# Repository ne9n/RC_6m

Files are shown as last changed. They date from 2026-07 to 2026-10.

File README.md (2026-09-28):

# 6-Meter Ham Band RC Transceiver Project

This project focuses on designing and building a modern 50MHz (6-meter) radio control system using the amateur radio bands. It features a high-power 1W transmitter and a high-sensitivity receiver, integrated into a vintage Kraft 7 transmitter case with a modern digital encoder.

## 📁 Repository Structure

### 📡 TX Hardware
- [PA_Design_Details.md](file:///TX_Hardware/PA_Design_Details.md): 1W RD01MUS2 Power Amplifier design and filtering.
- [Digital_Encoder_Conversion.md](file:///TX_Hardware/Digital_Encoder_Conversion.md): Strategy for upgrading the Kraft 7 to digital.
- [Kraft_Digital_UI_Wiring.md](file:///TX_Hardware/Kraft_Digital_UI_Wiring.md): Pinout for ESP32, ADS1115, and OLED.
- [TX_Schematic_Blueprint.md](file:///TX_Hardware/TX_Schematic_Blueprint.md): Pin-to-pin wiring for KiCad TX entry.
- [TX_BOM.md](file:///TX_Hardware/TX_BOM.md): Parts list for building the transmitter.
- [Analog_Wiring_Harness.md](file:///TX_Hardware/Analog_Wiring_Harness.md): Physical wiring for Kraft sticks and auxiliary pots.
- [Case_Modification_Guide.md](file:///TX_Hardware/Case_Modification_Guide.md): Cutting, mounting, and mechanical integration for the Kraft case.
- [Battery_Management_Design.md](file:///TX_Hardware/Battery_Management_Design.md): LiPo conversion and USB-C charging for the Kraft case.

### 🛩️ RX Hardware
- [RX_Design_Details.md](file:///RX_Hardware/RX_Design_Details.md): Front-end LNA, LT5560 upconverter (118.2MHz LO, ~169MHz IF), and Si4463 FSK receiver.
- [Receiver_Servo_Design.md](file:///RX_Hardware/Receiver_Servo_Design.md): Servo bus wiring and MCU integration.
- [RX_PCB_Design_Guide.md](file:///RX_Hardware/RX_PCB_Design_Guide.md): Physical layout, grounding, and stackup for the RX board.
- [RX_Schematic_Blueprint.md](file:///RX_Hardware/RX_Schematic_Blueprint.md): Pin-to-pin wiring for KiCad schematic entry.
- [RX_Power_Supply_Design.md](file:///RX_Hardware/RX_Power_Supply_Design.md): Servo bus filtering and 3.3V LDO design.
- [RX_BOM.md](file:///RX_Hardware/RX_BOM.md): Parts list for building the receiver.

### 💻 Software
- [Kraft_7_Firmware_Skeleton.ino](file:///Software/Kraft_7_Firmware_Skeleton.ino): Full code structure for dual ADC and Si5351 handler.
- [Firmware_Protocol_Spec.md](file:///Software/Firmware_Protocol_Spec.md): GFSK modulation logic and 50MHz packet structure.
- [Si5351_GFSK_Driver.cpp](file:///Software/Si5351_GFSK_Driver.cpp): C++ driver for frequency-pulling modulation.
- [Firmware_Implementation.md](file:///Software/Firmware_Implementation.md): GFSK modulation and Si4463 packet reception over SPI.
- [Trim_Implementation.md](file:///Software/Trim_Implementation.md): Digital trim logic and math.
- [Project_Recommendations.md](file:///Software/Project_Recommendations.md): ELRS and SimpleTX project guidance.
- [Telemetry_Protocol_Design.md](file:///Software/Telemetry_Protocol_Design.md): 2-way 50MHz data packet definition.

### 📜 System Documentation
- [System_Requirements.md](file:///System_Docs/System_Requirements.md): High-level project specifications and architectural goals.
- [6m_ham_rc_transceiver_design.md](file:///System_Docs/6m_ham_rc_transceiver_design.md): System architecture and block diagrams.
- [Initial_BOM.md](file:///System_Docs/Initial_BOM.md): Complete parts list for ordering.
- [PCB_Layout_Strategy.md](file:///C:/radio/System_Docs/PCB_Layout_Strategy.md): RF grounding and isolation rules.
- [PCB_Footprint_Guide.md](file:///C:/radio/System_Docs/PCB_Footprint_Guide.md): SMT footprints and assembly instructions.
- [PCB_Footprint_Mapping.md](file:///C:/radio/System_Docs/PCB_Footprint_Mapping.md): KiCad library mapping for all BOM parts.
- [RF_Range_Analysis.md](file:///C:/radio/System_Docs/RF_Range_Analysis.md): Theoretical range and link budget for 1W on 50MHz.
- **Datasheets**:
    - [SPF5043Z.pdf](file:///C:/radio/System_Docs/Datasheets/SPF5043Z.pdf): High-performance GaAs pHEMT MMIC LNA (50-4000 MHz).
    - [Murata_SFE_10.7_Reference.md](file:///C:/radio/System_Docs/Datasheets/Murata_SFE_10.7_Reference.md): Technical specs for the 10.7MHz IF Ceramic Filter. *Superseded (2026-09-28): the 10.7MHz IF was replaced by a ~169MHz IF into an Si4463.*
- **KiCad Projects**:
    - [TX_50MHz_1W.kicad_sch](file:///C:/radio/KiCad_Projects/TX_50MHz_1W/TX_50MHz_1W.kicad_sch): Main Transmitter Schematic.
    - [RX_50MHz_SDR.kicad_sch](file:///C:/radio/KiCad_Projects/RX_50MHz_SDR/RX_50MHz_SDR.kicad_sch): Main Receiver Schematic.
    - [RX_50MHz_SDR.net](file:///C:/radio/KiCad_Projects/RX_50MHz_SDR/RX_50MHz_SDR.net): Netlist for Receiver layout.
    - [TX_50MHz_1W.net](file:///C:/radio/KiCad_Projects/TX_50MHz_1W/TX_50MHz_1W.net): Netlist for Transmitter layout.
    - [KiCad_Import_Instructions.md](file:///C:/radio/KiCad_Projects/KiCad_Import_Instructions.md): Step-by-step guide to building the boards.

---

## 🛠️ Project Goals
1.  **2-Way Communication**: Telemetry feedback (Battery, RSSI) from plane to transmitter.
2.  **High Power**: 1W output for superior range and reliability on the 50MHz band.
3.  **Modern Digital Link**: Moving away from old analog PPM to a robust GFSK digital protocol (ELRS-inspired).
4.  **Vintage Aesthetic**: Preserving the classic feel of the Kraft 7 transmitter while providing modern performance.

---
*Maintained by ne9n.*

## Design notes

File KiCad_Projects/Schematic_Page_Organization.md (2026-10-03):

# KiCad Schematic Page Organization

**Status:** TX and RX hierarchies are implemented and netlist-verified. TX now has a dedicated Battery + Power page; RX has Controller/I/O, RF Front End, and IF Radio child pages.

## Design Rules

- Keep the transmitter and airborne receiver as separate KiCad projects.
- Use one root sheet per project as a block-level overview. Put circuitry on child sheets by function and signal flow.
- Use hierarchical labels/sheet pins or global labels for signals that cross child-sheet boundaries. Keep nets local when both endpoints are on the same sheet.
- Use global power symbols for power rails and ground rather than adding a hierarchy pin for every power connection.
- Preserve reference designators where practical. Run ERC and regenerate netlists after moving circuitry.

## Transmitter Project: `TX_50MHz_1W`

| Sheet | File | Contents |
|---|---|---|
| Root | `TX_50MHz_1W.kicad_sch` | TX system overview and named inter-sheet connections to four child sheets. |
| Battery + Power | `TX_Battery_Power.kicad_sch` | J8/J9 battery and 5V inputs, LMR33630 buck converter, AP2112 3.3V regulator, and support passives. |
| Controller + TX RF | `TX_Controller_RF.kicad_sch` | ESP32-S3, ADS1115s, controls/OLED, Si5351A, PA, T/R switch, transmit filter/antenna, and telemetry LNA/mixer. |
| Telemetry IF | `TX_Telemetry_IF.kicad_sch` | 169 MHz IF network/match, Si4463, 30 MHz crystal, and associated passive network. |
| USB Interface | `USB_Interface.kicad_sch` | Existing USB interface and battery charger child sheet. |

### TX Inter-sheet Nets

| Net | From | To | Purpose |
|---|---|---|---|
| `LNA_OUT`, `MIX_IN`, `MIX_IN_N`, `MIX_LO_N`, `MIX_OUT_N`, `IF_OUT_P` | Controller + TX RF / LNA and mixer | Telemetry IF / passive IF network | Analog front-end to IF boundary. |
| `SI_SCLK`, `SI_MOSI`, `SI_MISO`, `SI_nSEL`, `SI_nIRQ`, `SI_SDN` | Controller + TX RF / ESP32-S3 | Telemetry IF / Si4463 | SPI data, chip select, interrupt, and shutdown. |
| `5V`, `V_BATT` | Battery + Power / input and regulators | Controller + TX RF / 5V rail and PA supply | Named root ports connect the battery/power sheet to the controller/RF page. |
| `+3V3`, `GND` | Global power symbols | Controller + TX RF, Telemetry IF, USB Interface, and Battery + Power | Global supply and ground. |
| `EN`, `BOOT_IO0`, `U0RXD`, `U0TXD` | Controller + TX RF / ESP32-S3 | USB Interface / CP2102N and auto-reset | USB serial and reset-control nets. |

I2C and `TR_SW_CTRL` remain local to Controller + TX RF. Cross-sheet signals appear as root sheet pins with matching child hierarchical labels; power rails use global power symbols.

## Receiver Project: `RX_50MHz_SDR`

| Sheet | File | Contents |
|---|---|---|
| Root | `RX_50MHz_SDR.kicad_sch` | System-level overview and child-sheet connections. |
| Controller / I/O | `RX_Controller_IO.kicad_sch` | ESP32-S3, servo headers, INA219, 3.3 V regulator, and MCU-side control. |
| RF Front End | `RX_RF_Front_End.kicad_sch` | Antenna, T/R switch, LNA/matching, 50 MHz filter, mixer, and Si5351A LO / telemetry drive. |
| IF Radio | `RX_IF_Radio.kicad_sch` | 169 MHz IF filter/match and receive-only Si4463. |

### RX Inter-sheet Nets

| Net | From | To | Purpose |
|---|---|---|---|
| `SDA`, `SCL` | Controller / ESP32 and INA219 | RF Front End / Si5351A | I2C control bus. |
| `TR_SW`, `RX_EN` | Controller / ESP32 | RF Front End / switch and mixer | RX/TX path control and mixer enable. |
| `IF_OUT_P`, `MIX_OUT_N` | RF Front End / LT5560 | IF Radio / IF filter | Mixer IF outputs into the 169 MHz filter. |
| `SI_SCLK`, `SI_MOSI`, `SI_MISO`, `SI_nSEL`, `SI_nIRQ`, `SI_SDN` | Controller / ESP32 | IF Radio / Si4463 | SPI, interrupt, and shutdown signals. |

The RX root page now shows named sheet pins and short net-label wires for every cross-sheet signal. Matching hierarchical labels on the child pages connect those ports. RF-only nets, servo signals, USB, and `5V_RAIL` stay local; `3V3` and `GND` use global power symbols.

## Power Nets

Use global power symbols for rails instead of hierarchy pins. The TX schematic uses `GND`, `+3V3`, and `V_BATT`; `5V` is an explicit inter-sheet signal. The RX schematic uses its existing `GND`, `+3V3`/`3V3`, and `5V_RAIL` nets. Keep these names as shown in each schematic.

## Conversion Notes

1. The TX root now exposes the cross-sheet nets as sheet pins; matching hierarchical labels are on each connected child page.
2. The TX and RX tables record root sheet pins and matching child hierarchical labels. Keep one consistent name per signal within each project.
3. The checked-in exported `.net` files are stale: they still show the old 10.7 MHz filter / ADC receive path and do not include the current Si4463 receive chain. Regenerate them from the updated schematics after the hierarchy conversion.
4. Run ERC on each project and inspect the generated netlists to confirm every listed cross-sheet signal reaches the intended pins.

## Related Design References

- [TX schematic blueprint](../TX_Hardware/TX_Schematic_Blueprint.md)
- [RX schematic blueprint](../RX_Hardware/RX_Schematic_Blueprint.md)
- [Project wiring instructions](work_instructions.md)

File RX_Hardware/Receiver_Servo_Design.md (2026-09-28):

# 6m RC Receiver: Back-End & Servo Connections

This document details the hardware and software required to turn the 50MHz RF signal into physical control for your airplane's servos.

## 1. Receiver Architecture (Back-End)

The RF deck upconverts the 50MHz signal to a ~169MHz IF and an **Si4463** FSK receiver demodulates it in hardware; the MCU (ESP32-S3) reads decoded packets over SPI (see `RX_Design_Details.md`). The MCU then generates **PWM (Pulse Width Modulation)** signals for the servos.

### 1.1 MCU Choice: ESP32-S3
The ESP32-S3 is recommended for the receiver because:
- **High Speed**: Dual-core 240MHz is plenty for packet handling, hopping and servo output.
- **PWM Peripherals**: The `MCPWM` (Motor Control PWM) hardware is perfect for generating jitter-free servo signals.
- **Tiny Form Factor**: Available in small modules (ESP32-S3-WROOM-1) suitable for aircraft.

---

## 2. Servo Connection Schematic

Standard RC servos use a 3-pin connector: **GND, 5V (VCC), and Signal (PWM)**.

### 2.1 Wiring Diagram
```mermaid
graph TD
    subgraph "50MHz RF Deck"
        RF["LT5560 Upconverter + 169MHz IF + Si4463"]
    end

    subgraph "Receiver Brain (ESP32-S3)"
        ADC["SPI (Si4463 packets)"]
        MCU["ESP32-S3 Core"]
        PWM["PWM Outputs (Ch 1-8)"]
    end

    subgraph "Servo Bus (Power Rail)"
        BEC["ESC / BEC (5V Input)"]
        S1["Servo 1 (Ail)"]
        S2["Servo 2 (Ele)"]
        S3["Servo 3 (Thr)"]
        S4["Servo 4 (Rud)"]
    end

    RF -- "Decoded packets" --> ADC
    ADC --> MCU
    MCU --> PWM
    PWM -- "Signal" --> S1 & S2 & S3 & S4
    BEC -- "5V Rail" --> S1 & S2 & S3 & S4
```

### 2.2 Servo Pin Mapping (ESP32)
| Channel | Function | ESP32 Pin | Note |
| :--- | :--- | :--- | :--- |
| **CH 1** | Aileron | GPIO 4 | 50Hz PWM, 1000-2000us (the old `ADC_IF` net on IO4 is removed with the Si4463 redesign, clearing this clash) |
| **CH 2** | Elevator | GPIO 5 | 50Hz PWM |
| **CH 3** | Throttle | GPIO 6 | Connects to ESC Signal |
| **CH 4** | Rudder | GPIO 7 | 50Hz PWM |
| **CH 5** | Aux 1 | GPIO 15 | Gear / Flaps |
| **CH 6** | Aux 2 | GPIO 16 | |
| **CH 7** | Aux 3 | GPIO 1 | |
| **CH 8** | Aux 4 | GPIO 2 | |

---

## 3. Power Management (The Servo Bus)

**CRITICAL**: Servos draw significant current (up to 2A during stalls). Do **NOT** power servos directly from the ESP32's 3.3V regulator.

1.  **Common Rail**: Create a high-current 5V rail (the "Servo Bus") on your PCB.
2.  **BEC Input**: Use the 5V output from your Electronic Speed Controller (ESC) to power this rail.
3.  **Isolation**: Add a large capacitor (470uF - 1000uF) on the 5V rail to prevent voltage dips (Brown-outs) when servos move rapidly, which could reset the ESP32.

---

## 4. PWM Firmware (ESP32 C++ Snippet)

Using the ESP32 `ESP32Servo` library for easy implementation.

```cpp
#include <ESP32Servo.h>

Servo aileron;
Servo elevator;

void setup() {
    // Standard RC PWM: 50Hz, 1000us min, 2000us max
    aileron.attach(4, 1000, 2000); 
    elevator.attach(5, 1000, 2000);
}

void updateServos(int ail_val, int ele_val) {
    // ail_val and ele_val are decoded from the 50MHz radio link
    aileron.writeMicroseconds(ail_val);
    elevator.writeMicroseconds(ele_val);
}
```

---

## 5. Physical Layout Recommendation
- **Servo Headers**: Use standard 3-pin 0.1" (2.54mm) male headers arranged in a row.
- **Antenna**: A 1.5m thin wire (28AWG) trailing from the plane. Ensure it is routed away from the servo wires to minimize interference.

---
*Created for the 50MHz Ham Band RC Project.*

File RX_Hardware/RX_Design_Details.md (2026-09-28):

# 6m RC Receiver Design Details (LT5560 + Si4463)

This document describes the design of the high-sensitivity receiver for the 50MHz RC link, focusing on the mixer and Intermediate Frequency (IF) stage.

## 1. Front-End (LNA)
- **Component**: **SPF5043Z** MMIC.
- **Function**: Provides ~15dB of gain with a very low noise figure (< 0.8dB).
- **Matching**: Requires a simple inductor/capacitor match for 50MHz at the input and output.
- **Protection**: A pair of BAV99 diodes should be placed at the input to protect the LNA from high-power pulses if the T/R switch fails.

---

## 2. Mixer Stage (Up-Converter)
The **LT5560** active mixer is kept, but it now **up-converts** the 6m signal to a VHF IF
instead of down-converting to 10.7MHz (see section 3 for why).

- **RF Input**: 50.100 - 51.000 MHz (from LNA / 50MHz BPF).
- **LO Input**: **118.200 MHz, fixed** (Si5351A CLK0, on its own PLL -- PLLA 709.2MHz, integer MultiSynth /6).
- **IF Output**: **IF = RF + LO** -> 168.300 - 169.200 MHz (US RC channels 50.800-50.980 -> 169.000-169.180 MHz).
  Sum mixing, so there is no spectral inversion: an FSK mark stays a mark.
- **Output network**: must now be tuned for ~169MHz rather than 10.7MHz. Both open-collector IF
  outputs need a DC path to VCC -- follow the LT5560 datasheet output network.
- **Spurs / image**: image = IF + LO ~ 287MHz; the 2xRF - LO = IF response sits at ~143.6MHz.
  Both are removed by the 50MHz BPF ahead of the mixer. LO (118.2MHz) and RF (50MHz)
  feedthrough are removed by the IF band-pass and the Si4463's own channel filter.

---

## 3. IF Filtering & Demodulation -- Si4463 packet receiver
- **IF Filter**: 3-pole LC band-pass, centre ~168.75MHz, ~3-5MHz bandwidth, 50 ohm (values TBD --
  design and verify with SPICE). Replaces the Murata SFE10.7 ceramic filter. It only needs to
  pass the hop band and reject LO/RF feedthrough; channel selectivity is done inside the Si4463.
- **Demodulator**: **Si4463-C2A-GM** (Silicon Labs EZRadioPRO, QFN-20, **active part**), used as
  a **receive-only** 2(G)FSK packet receiver at the 169MHz IF. Frequency range 142-1050MHz, so it
  cannot tune 50MHz directly -- hence the up-converter.
  - **RF input**: RXp/RXn through the differential LNA match from Silicon Labs AN643 (169MHz values).
  - **Reference**: its own **30.000MHz crystal** (internal tunable load caps, `GLOBAL_XO_TUNE`),
    not shared with the Si5351A, to keep LO spurs off the reference.
  - **Host interface**: SPI (<=10MHz, mode 0) + nIRQ + SDN to the ESP32-S3.
  - **Does in hardware**: channel filtering, demodulation, **AFC**, preamble + sync-word (0x1D4A)
    detection, packet FIFO, **RSSI**. Firmware only reads the 22-byte payload, checks CRC8 and
    drives the servos.
  - **Frequency hopping**: the LO stays fixed; each hop is just `START_RX` on the next Si4463
    channel number -- no Si5351 retuning or I2C traffic on the receive side.
- **Frequency error budget** (worst case, +-20ppm parts): TX carrier ~1kHz + LO ~2.4kHz + Si4463
  XO ~3.4kHz = ~6.8kHz -- more than the +-5kHz deviation. **Enable the Si4463 AFC**, and/or trim
  at build (Si5351 correction factor + `GLOBAL_XO_TUNE`).
- **IF choice**: 169MHz isn't an empty band anywhere (US land-mobile/paging nearby, EU 169.4MHz
  metering), so keep the IF section compact and shielded. If a local interferer shows up, the IF
  can be moved anywhere in ~142-200MHz with the LO kept <= ~150MHz.

  **Revision history -- why not the earlier approaches:**
  1. *IF undersampling (original)*: the ESP32-S3 ADC is capped at 83.3kSPS
     (`SOC_ADC_SAMPLE_FREQ_THRES_HIGH`), ~30x too slow for the 230kHz-wide 10.7MHz IF.
  2. *Single-chip FM-IF detectors* (MC3361/MC3372, SA604A, NJM2211): all obsolete (checked 2026-09-22).
  3. *CD74HC4046A PLL discriminator* (2026-09-22 revision): the HC4046 VCO is marginal at
     10.7MHz on 3.3V, needs a limited IF, and gives no AFC/RSSI/sync/CRC -- all left to firmware.
  4. *AX5043* (native 27-1050MHz, no conversion needed): out of production.
  5. *CC1101*: 300MHz minimum would need an LO > 250MHz, beyond the Si5351A's ~200MHz range.

---

## 4. T/R Switching
To protect the receiver during 1W transmission:
- **Component**: **BGS12PL6** RF Switch.
- **Isolation**: > 30dB at 50MHz.
- **Switching Speed**: < 1us (Critical for fast telemetry turnaround).

---

## 5. Summary Schematic Diagram

```mermaid
graph LR
    ANT["Antenna"] --> SW["RF Switch"]
    SW -- "TX Path" --> PA["1W PA"]
    SW -- "RX Path" --> BPF["50MHz BPF"]
    BPF --> LNA["SPF5043Z"]
    LNA --> MIXER["LT5560 Up-Mixer"]
    LO["Si5351A CLK0 (LO 118.2MHz)"] --> MIXER
    MIXER -- "IF 168.3-169.2MHz" --> IF_FILT["169MHz LC BPF"]
    IF_FILT --> MATCH["AN643 RX Match"]
    MATCH --> SI["Si4463 FSK Receiver"]
    XTAL["30MHz Crystal"] --> SI
    SI -- "SPI + nIRQ" --> MCU["ESP32-S3"]
```

---
*Reference: Analog Devices LT5560 Datasheet; Silicon Labs Si4464/63/61/60 Datasheet and AN643 (Si446x RX LNA matching).*

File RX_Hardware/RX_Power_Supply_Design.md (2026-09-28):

# 50MHz Receiver: Power Supply Design

This document describes the power distribution system for the aircraft-side receiver, converting high-current servo power to stable RF-grade 3.3V logic.

## 1. Power Source (BEC/ESC)
The receiver does not have its own battery. It draws power from the **5V or 6V rail** provided by the Electronic Speed Controller (ESC) or a standalone Battery Eliminator Circuit (BEC) via any of the servo headers.

- **Input Range**: 4.5V to 7.0V (Standard RC Servo Bus).
- **Current Requirement**: ~150mA (ESP32-S3 + RF stages) + Si4463 RX current (per datasheet, TBD) + Servo loads.

---

## 2. Power Architecture

```mermaid
graph LR
    SERVO[Servo Bus 5V-6V] --> FILT[LC Pi-Filter]
    FILT --> LDO[3.3V LDO AP2112K]
    LDO --> RF["RF Stages: LNA, Mixer, Synth, Si4463"]
    LDO --> MCU[ESP32-S3]
    SERVO --- SERVOS[Servos: Ail, Ele, Thr, Rud]
    BATT[Flight Battery] --> INA[INA219 Sensor]
    INA --> ESC[To ESC]
    INA -- I2C --> MCU
```

---

## 3. Voltage Regulation (3.3V)
We use a high-quality **Low Dropout Regulator (LDO)** instead of a switching buck converter to prevent switching noise from interfering with the sensitive 50MHz LNA.

### 3.1 Component: AP2112K-3.3
- **Output**: 3.3V @ 600mA.
- **Why**: Excellent ripple rejection and very low noise.

---

## 4. RF Noise Isolation
Servos generate significant "inductive kickback" and electrical noise. To protect the RF sensitivity, we implement two levels of filtering:

### 4.1 Input LC Filter (The "Moat")
A Pi-filter at the input of the LDO prevents servo noise from entering the logic rails.
- **L1**: 10 uH Power Inductor (0805 or 1206).
- **C1/C2**: 10 uF Ceramic Capacitors.

### 4.2 Local Decoupling
Each RF chip (SPF5043Z, LT5560) must have its own 10nF + 100pF capacitor pair located within 2mm of the VCC pin.

---

## 5. Reverse Polarity Protection
RC connectors can sometimes be plugged in backwards.
- **Protection**: A **Schottky Diode (e.g., SS14)** should be placed in series with the 5V input to the LDO to prevent magic smoke if the ESC is connected incorrectly.

---

## 6. Telemetry Monitoring (INA219)
To send battery status back to the ground station, an **INA219 I2C sensor** is placed in-line with the main flight battery.
- **V_BATT Monitoring**: Measures the 2S-4S LiPo voltage.
- **Current Monitoring**: Measures the total current draw of the propulsion system.
- **Interface**: Connects to the ESP32-S3 via the same I2C bus as the Si5351A.

---

## 7. Wiring Summary

| Point | Connection | Purpose |
| :--- | :--- | :--- |
| **Servo Rail (+)** | To Diode Anode | Main Power In |
| **Diode Cathode** | To LC Filter In | Protected Power |
| **LDO Vout** | To ESP32 & RF VCC | Clean 3.3V |
| **INA219 IN+** | To Battery (+) | Current Sensing In |
| **INA219 IN-** | To ESC (+) | Current Sensing Out |
| **Common GND** | Ground Plane | Return Path |

---
*Note: Ensure the ground plane under the LDO is solid to act as a small heatsink.*

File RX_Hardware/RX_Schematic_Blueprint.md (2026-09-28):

# 50MHz Receiver: KiCad Schematic Blueprint

## Visual Schematic Reference
RX Schematic Reference

## 1. Functional Block Diagram

```mermaid
graph LR
    ANT[Antenna] --> SW[BGS12PL6 T/R Switch]
    SW -- RX Path --> LNA_MATCH[Input Match]
    LNA_MATCH --> LNA[SPF5043Z]
    LNA --> BPF[50MHz BPF]
    BPF --> MIX[LT5560 Mixer]
    LO[Si5351A CLK0 LO 118.2MHz] --> MIX
    SW -- TX Path --> TELEM_DRIVE[Si5351A CLK1]
    MIX -- "IF 168.3-169.2MHz" --> IF_FILT[169MHz LC BPF]
    IF_FILT --> RXMATCH[AN643 RX Match]
    RXMATCH --> SI4463[Si4463 FSK Receiver]
    SI4463 -- SPI + nIRQ --> ESP
    BATT[Flight Battery] --> INA[INA219 Sensor]
    INA --> ESC[To ESC]
    INA -- I2C --> ESP[ESP32 MCU]
```

---

## 2. Component Netlist (Pin-to-Pin)

### 2.1 RF Switch (T/R Switch)
**IC: BGS12PL6 (TSLP-6)**

| Pin | Name | Connection | Note |
| :--- | :--- | :--- | :--- |
| 1 | RF2 | To Si5351A CLK1 (via 100pF) | Telemetry TX Path |
| 2 | GND | Ground Plane | |
| 3 | RF1 | To LNA Match Input | Control RX Path |
| 4 | CTRL | ESP32 IO10 (TR_SW) | High = TX, Low = RX |
| 5 | ANT | To Antenna Header | 50 Ohm Port |
| 6 | VDD | 3.3V Rail | Decouple with 0.1uF |

### 2.2 RF Front-End (LNA)
**IC: SPF5043Z (SOT-343)**

| Pin | Name | Connection | Note |
| :--- | :--- | :--- | :--- |
| 1 | RFin | From Switch RF1 (via 100pF) | 50 Ohm Trace |
| 2 | GND | Ground Plane | Use multiple vias |
| 3 | RFout/VCC | To Mixer (via 100pF Cap + RFC) | Power fed via Inductor |
| 4 | GND | Ground Plane | |

### 2.3 Mixer Stage (up-converter, 50MHz -> 169MHz IF)
**IC: LT5560 (DFN-8)**

| Pin | Name | Connection | Note |
| :--- | :--- | :--- | :--- |
| 1 | IN+ | From LNA Output (C_coupling) | RF Input |
| 2 | IN- | AC Ground (100pF to GND) | |
| 3 | EN | ESP32 IO21 (RX_EN) | Logic High to Enable |
| 4 | VCC | 3.3V Rail | Decouple with 10nF |
| 5 | OUT+ | To 169MHz IF BPF (via output match) | IF Output, ~169MHz; DC path to VCC per LT5560 datasheet |
| 6 | OUT- | AC Ground (10nF to GND) | Also needs its DC path to VCC (open collector) |
| 7 | LO+ | From Si5351A CLK0 | Local Oscillator, 118.200MHz fixed |
| 8 | LO- | AC Ground (100pF to GND) | |

### 2.4a IF Band-Pass Filter (replaces 10.7MHz ceramic filter)
3-pole LC band-pass, 50 ohm, centre ~168.75MHz, ~3-5MHz bandwidth (passes 168.3-169.2MHz).
Rejects LO (118.2MHz) and RF (50MHz) feedthrough from the mixer. Values TBD -- design and
verify with SPICE before layout.

### 2.4b FSK Packet Receiver
**IC: Si4463-C2A-GM (QFN-20, 4x4mm, exposed pad)** -- see `RX_Design_Details.md` section 3.
Receive-only: the TX and TXRAMP pins are left open and the chip is never put in TX state.
Replaces the CD74HC4046APWR PLL discriminator and the IF/baseband-to-ADC path (`ADC_IF` on IO4 is deleted).

| Pin | Name | Connection | Note |
| :--- | :--- | :--- | :--- |
| 1 | SDN | ESP32 IO18 (SI_SDN) | High = shutdown; drive low to run |
| 2 | RXp | From IF BPF via RX match | Differential LNA match per Silicon Labs AN643 (169MHz) |
| 3 | RXn | From IF BPF via RX match | |
| 4 | TX | Not Connected | Receive-only |
| 5 | NC | Not Connected | |
| 6 | VDD | 3.3V Rail | Decouple 100nF + 1uF |
| 7 | TXRAMP | Not Connected | Receive-only |
| 8 | VDD | 3.3V Rail | Decouple 100nF + 1uF (+10pF close to the pin) |
| 9 | GPIO0 | Test point | Optional RX_STATE |
| 10 | GPIO1 | Test point | Optional CTS (CTS is also polled over SPI) |
| 11 | nIRQ | ESP32 IO17 (SI_nIRQ) | Open drain, 10k pull-up to 3.3V |
| 12 | SCLK | ESP32 IO12 (FSPICLK) | SPI <=10MHz, mode 0 |
| 13 | SDO | ESP32 IO13 (FSPIQ) | MISO |
| 14 | SDI | ESP32 IO11 (FSPID) | MOSI |
| 15 | nSEL | ESP32 IO14 | Chip select (software-driven via GPIO matrix; IO10 is the T/R switch CTRL) |
| 16 | XOUT | 30.000MHz Crystal | Internal load caps (`GLOBAL_XO_TUNE`), no external caps |
| 17 | XIN | 30.000MHz Crystal | |
| 18 | GND | Ground Plane | |
| EP | GND | Ground Plane | Via-stitched exposed pad |

ESP32 pins: FSPI IOMUX pins for SCLK/MOSI/MISO, with CS on IO14 because IO10 is the T/R switch
CTRL. As captured in `RX_50MHz_SDR.kicad_sch` (U9) on 2026-09-28.

### 2.4 Synthesizer
**IC: Si5351A (MSOP-10)**

| Pin | Name | Connection | Note |
| :--- | :--- | :--- | :--- |
| 1 | VDD | 3.3V Rail | Decouple 0.1uF |
| 2 | XA | 26MHz Crystal | |
| 3 | XB | 26MHz Crystal | |
| 4 | SCL | ESP32 GPIO 9 | I2C Clock |
| 5 | SDA | ESP32 GPIO 8 | I2C Data |
| 6 | CLK0 | To LT5560 Pin 7 | LO Output, 118.200MHz fixed, PLLA |
| 7 | CLK1 | To BGS12 Pin 1 (via 100pF) | Telemetry TX Output, PLLB (FSK updates never touch the LO) |

### 2.5 Telemetry Sensor
**IC: INA219 (SOT-23-8)**

| Pin | Name | Connection | Note |
| :--- | :--- | :--- | :--- |
| 1 | IN+ | Main Battery Positive | Source |
| 2 | IN- | ESC Positive Lead | Load |
| 3 | GND | System Ground | |
| 4 | VS | 3.3V Rail | |
| 5 | SCL | I2C Clock (Bus) | |
| 6 | SDA | I2C Data (Bus) | |
| 7 | A0 | GND | Address 0x40 |
| 8 | A1 | GND | |

### 2.6 Power Supply (3.3V Regulator)
**IC: AP2112K-3.3 (SOT-23-5)**

| Pin | Name | Connection | Note |
| :--- | :--- | :--- | :--- |
| 1 | VIN | From Servo 5V (via SS14 Diode) | LC Filtered |
| 2 | GND | Ground Plane | |
| 3 | EN | Connect to VIN | Always On |
| 4 | NC | Not Connected | |
| 5 | VOUT | 3.3V Logic Rail | Decouple 10uF |

---

## 3. Passive Component Values (50MHz)

| RefDes | Value | Purpose |
| :--- | :--- | :--- |
| **C_coupl** | 100 pF | DC Blocking (RF Path) |
| **L_match** | 220 nH | Input Matching for 50MHz |
| **C_decoup** | 10 nF | High-frequency bypassing |
| **RFC** | 1.0 uH | RF Choke for LNA Power |
| **IF_FILT** | 169 MHz | 3-pole LC band-pass, ~3-5MHz BW, 50 ohm -- values TBD (SPICE) |
| **LT5560 IF match** | TBD | Output network for ~169MHz (replaces the 10.7MHz output match) |
| **Si4463 RX match** | TBD | Differential LNA match, 169MHz values from Silicon Labs AN643 |
| **Y (Si4463)** | 30.000 MHz | Crystal, 3225, <=+-10ppm preferred; no load caps (internal) |
| **R_nIRQ** | 10 kOhm | nIRQ pull-up to 3.3V |
| **C_Si4463** | 100nF + 1uF per VDD pin | Si4463 decoupling |

---

## 4. KiCad Library Suggestions
- **ESP32-S3**: Use the `Espressif` official KiCad library.
- **Si4463**: `RF:Si4463` in the stock KiCad library, footprint `Package_DFN_QFN:QFN-20-1EP_4x4mm_P0.5mm_EP2.6x2.6mm_ThermalVias`.
- **Si5351A**: Found in the `RF_Synthesizer` library.
- **SPF5043Z**: You may need to create a custom SOT-343 symbol, or use a generic 4-pin LNA symbol.
- **LT5560**: Use a generic `DFN-8-1EP_2x2mm` footprint.

## 5. Next Steps in KiCad
1.  **Symbols**: Add the ESP32-S3, Si5351A and Si4463 from the standard libraries. Delete the 10.7MHz filter and the `ADC_IF` net.
2.  **Custom Symbols**: Create the LT5560 and SPF5043Z symbols using the pin tables above.
3.  **Hierarchy**: Use **Global Labels** for `3.3V`, `GND`, `SDA`, and `SCL` to keep the schematic clean.
4.  **Grounding**: Ensure the **Exposed Pad (EP)** on the LT5560 is connected to the GND net.

---
*Created for the 6m RC Receiver Build.*

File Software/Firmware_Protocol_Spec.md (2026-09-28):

# Kraft-6M: Firmware Implementation & Protocol Guide

This document details the software logic required to run the 50MHz digital RC link using the ESP32-S3 and Si5351A.

## 1. Modulation Logic (Si5351A GFSK)
Unlike 2.4GHz chips (LoRa/CC2500), the Si5351A is a clock generator. To perform **Gaussian Frequency Shift Keying (GFSK)**, we must "pull" the frequency of the oscillator in real-time.

### 1.1 Bit Representation
- **Center Frequency ($f_c$):** 50.100 MHz
- **Frequency Deviation ($\Delta f$):** ±5 kHz (project standard -- older docs/code used ±2.4 kHz; the Si4463 receivers are configured for ±5 kHz, so the TX must match)
- **Logic '1':** $f_c + 5$ kHz
- **Logic '0':** $f_c - 5$ kHz

### 1.2 Implementation
We use the Si5351's **VCXO (Voltage Controlled Crystal Oscillator)** capability or rapidly update the `MultiSynth` registers via I2C.
- **Data Rate:** 2400 bps or 4800 bps (to keep bandwidth narrow and range high).
- **Encoding:** **NRZ, no whitening** (bring-up default). The Si4463 receiver can't decode 8b/10b, so that option is dropped; Manchester is supported in Si4463 hardware and is the fallback if long runs cause bit errors (doubles the on-air symbol rate).
- **Preamble:** at least **5 bytes (40 bits) of alternating `0x55`** ahead of the sync word, so the Si4463's AFC and preamble detector settle.
- **Separate PLLs:** the Si5351A's CLK0 (FSK carrier) and CLK1 (118.2MHz receive LO) sit on PLLA and PLLB, so FSK updates never disturb the LO.

---

## 2. Packet Structure (24 Bytes)
Each frame transmitted every 20ms (50Hz) follows this structure:

| Byte | Field | Description |
| :--- | :--- | :--- |
| 0-1 | **Sync Word** | 0x1D4A (detected by the Si4463 packet handler; bytes 2-23 are the fixed-length 22-byte payload) |
| 2-17| **Channels** | 8 Channels x 16-bits (from ADS1115) |
| 18 | **Flags** | Failsafe bit, Telemetry request bit |
| 19-22| **ID** | 32-bit Unique Transmitter ID |
| 23 | **CRC8** | Cyclic Redundancy Check (Polynomial: 0x07) -- computed/checked in firmware; Si4463 hardware CRC disabled |

---

## 3. Transmitter (TX) Logic Flow
1.  **Read ADCs**: Poll both ADS1115 modules for stick and aux knob positions.
2.  **Apply Trims**: Add/Subtract the digital trim values stored in ESP32 NVS.
3.  **Pack Frame**: Convert 16-bit values into the 24-byte buffer.
4.  **Bit-Bang RF**:
    - Iterate through the buffer bit-by-bit.
    - Change Si5351 CLK0 frequency for each bit.
    - Maintain precise timing using ESP32 High-Resolution Timers (`esp_timer`).
5.  **Listen for Telemetry**: Briefly switch the receiver (if implemented) or check for ACKs.

---

## 4. Receiver (RX) Logic Flow (Si4463)
The 6m signal is upconverted to ~169MHz (LT5560 + fixed 118.2MHz Si5351A LO) and demodulated by an **Si4463**; the ESP32-S3 reads finished packets over SPI. (The earlier SDR/IF-sampling and 4046 PLL-discriminator flows are superseded -- see `Firmware_Implementation.md`.)
1.  **Init**: SDN low, wait for POR, load the WDS/Radio Configurator config (`radio_config_si4463.h`) over SPI, polling CTS. AFC enabled.
2.  **Listen**: `START_RX` on the current hop channel, fixed packet length.
3.  **Packet**: on nIRQ (PACKET_RX), read the 22-byte payload from the RX FIFO and the latched RSSI.
4.  **CRC Check**: If the firmware CRC8 passes, update the PWM outputs for the servos.
5.  **Failsafe**: If no valid packet is received for 500ms, move servos to neutral/preset.

---

## 5. Frequency Hopping (FHSS)
To comply with Ham Radio best practices and avoid interference:
- Define a table of 16 frequencies (e.g., 50.1, 50.2, ... 50.8 MHz).
- Both TX and RX hop to the next frequency every 100ms.
- **Receive side**: hopping is done by the **Si4463 channel number** (`START_RX` on the next channel; channel step = hop spacing). The 118.2MHz LO stays fixed -- no Si5351A retune or I2C traffic on the receive side per hop. The transmit side still retunes Si5351A CLK0.
- **Note**: the example table (50.1-50.8 MHz) overlaps the 6m weak-signal CW/SSB segment (50.0-50.3 MHz). The US RC channels are 50.800-50.980 MHz -- review the hop table before use.
- Hopping sequence is determined by the 32-bit `Transmitter ID`.

---
*Created for the Kraft-6M Project.*

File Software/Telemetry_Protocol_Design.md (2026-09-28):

# 50MHz RC Telemetry Protocol Design

This document defines the 2-way data packet structure for sending airplane status (telemetry) back to the Kraft transmitter over the 50MHz link.

## 1. Physical Layer (PHY)
- **Modulation**: GFSK (Gaussian Frequency Shift Keying).
- **Data Rate**: 50 kbps (Balanced for range vs latency).
- **Frequency**: 50.0 - 54.0 MHz (User selectable).
- **Duplex**: Time Division (TDD). 90% TX (Control), 10% RX (Telemetry).
- **Receiver (TX board)**: the telemetry is received by an **Si4463** (LT5560 upconversion to a ~169MHz IF, Si5351A LO fixed at 118.2MHz -- see `RX_Hardware/RX_Design_Details.md`). The Si4463 has one PHY configuration, so the telemetry downlink must use the **same PHY as the control link**: 2FSK/2GFSK, 2400 bps, +-5kHz deviation, >=5-byte `0x55` preamble, `0x1D4A` sync word, NRZ, fixed length (see `Firmware_Protocol_Spec.md`). The 50 kbps rate and 1-byte `0x99` sync below are **superseded** -- the Si5351A I2C modulator can't reach 50 kbps anyway.

---

## 2. Packet Structure

Each telemetry packet is **12 bytes** long to keep the transmission window short.

| Byte | Field | Description | Range |
| :--- | :--- | :--- | :--- |
| 0 | **Sync** | Sync Word (0x99) -- superseded: the Si4463 packet handler detects the 2-byte `0x1D4A` sync ahead of this byte | Fixed |
| 1 | **Device ID** | Unique ID for the Receiver | 0-255 |
| 2-3 | **Batt_V** | Main Flight Battery Voltage (mV) | 0 - 65535 mV |
| 4-5 | **Current** | Instantaneous Current (mA) | 0 - 65535 mA |
| 6 | **RSSI** | Signal Strength at Airplane (latched RSSI from the RX board's Si4463) | -128 to 0 dBm |
| 7 | **Link Quality**| Packet success rate | 0 - 100% |
| 8-9 | **Altitude** | Barometric or GPS altitude (m) | Signed Integer |
| 10 | **Flags** | Alarm bits (Low Batt, Failsafe) | Bitmask |
| 11 | **CRC8** | Error Checking (Dallas/Maxim) | Calculated |

---

## 3. Firmware Logic (ESP32-S3)

### 3.1 On the Airplane (RX)
Every 100ms, the receiver stops listening for control pulses, switches the Si5351A to the Telemetry frequency, and bursts the 12-byte packet.

### 3.2 On the Transmitter (TX)
The transmitter listens in the "gap" between its control frames. If a valid telemetry packet is received:
1.  **CRC Check**: Validate packet integrity (in firmware; the Si4463's hardware CRC is disabled). The packet arrives over SPI from the TX board's Si4463 on nIRQ (PACKET_RX); the Si4463's latched RSSI gives the ground-side signal strength.
2.  **Display Update**: Push the `Batt_V` and `RSSI` to the SH1106 OLED display.
3.  **Haptic/Audio**: Trigger a beep if `Flags` bit 0 (Low Battery) is set.

---

## 4. Telemetry Alarm Thresholds

| Sensor | Warning (Beep) | Critical (Continuous) |
| :--- | :--- | :--- |
| **LiPo 3S** | 10.8V (3.6V/cell) | 10.2V (3.4V/cell) |
| **RSSI** | -95 dBm | -105 dBm (Risk of Failsafe) |
| **Link Quality**| < 70% | < 50% |

---

## 5. Next Steps
- Implement the `CRC8` calculation function in the ESP32 code.
- Add an **INA219 I2C Current Sensor** to the receiver BOM for high-accuracy current/voltage sensing.

---
*Reference: ExpressLRS (ELRS) Telemetry Format & CRSF Protocol.*

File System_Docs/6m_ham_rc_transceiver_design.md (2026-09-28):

# 6m (50MHz) Amateur Radio RC Transceiver Design

This document details the design for a modern, high-performance 2-way digital radio control and telemetry system operating in the 50MHz (6-meter) Amateur Radio band.

## 1. Project Overview
- **Frequency Band**: 50.0 – 54.0 MHz (Target: 50.8 – 51.0 MHz RC Window).
- **Communication Type**: 2-Way Digital Link (Control + Telemetry).
- **Modulation**: GFSK (Gaussian Frequency Shift Keying).
- **Architecture**: Si5351A carrier/LO + LT5560 upconverting mixer + **Si4463** FSK receiver (6m upconverted to a ~169MHz IF) - all in-production parts. (Revised 2026-09-28: replaces the SA612 / 10.7MHz IF / software-demod receiver.)

---

## 2. System Architecture

```mermaid
graph TD
    subgraph "Ground Station (TX - 1W)"
        G_MCU["ESP32 (ELRS Logic)"]
        G_Si["Si5351A (Freq Gen)"]
        G_PA["RD01MUS1 (1W PA)"]
        G_LPF["7-Pole Low Pass Filter"]
        G_Switch["RF T/R Switch"]
        G_Whip["1.5m Telescoping Whip"]

        G_MCU -- "I2C (Freq Shift)" --> G_Si
        G_Si -- "50MHz" --> G_PA
        G_PA --> G_Switch
        G_Switch <--> G_LPF <--> G_Whip
        G_Switch -- "RX Path" --> G_LNA["SPF5043Z LNA + LT5560 Mixer"]
        G_Si -- "LO 118.2MHz (CLK1)" --> G_LNA
        G_LNA -- "169MHz IF (LC BPF)" --> G_RX["Si4463 FSK Receiver"]
        G_RX -- "SPI (packets, RSSI)" --> G_MCU
    end

    subgraph "Airplane Receiver (RX - Mini)"
        A_MCU["ESP32-S3"]
        A_Si["Si5351A (LO/TX)"]
        A_Mixer["SPF5043Z LNA + LT5560 Mixer"]
        A_RX["Si4463 FSK Receiver"]
        A_BPF["50MHz Bandpass"]
        A_Wire["1.5m Trailing Wire"]

        A_Wire <--> A_BPF <--> A_Mixer
        A_Si -- "LO 118.2MHz (CLK0)" --> A_Mixer
        A_Mixer -- "169MHz IF (LC BPF)" --> A_RX
        A_RX -- "SPI (packets, RSSI)" --> A_MCU
        A_Si -- "Telemetry TX" --> A_BPF
        A_MCU -- "I2C" --> A_Si
    end

    G_Whip -. "50MHz Control" .-> A_Wire
    A_Wire -. "Telemetry" .-> G_Whip
```

---

## 3. Key Components

### 3.1 RF & Logic
| Component | Part Number | Role | Description |
| :--- | :--- | :--- | :--- |
| **Frequency Gen** | [Si5351A-B-GT](https://www.silabs.com/timing/clock-generators/si5351-any-frequency-i2c-programmable-clock-generator) | TX & LO | Generates 50MHz carrier and handles FSK modulation via I2C register pulling. |
| **Power Amp** | [RD01MUS1](https://www.mitsubishielectric.com/semiconductors/content/product/highfrequency/rfmosfet/rd01mus1.pdf) | TX Boost | 1W VHF Silicon MOSFET. Provides robust range for the ground link. |
| **Mixer** | LT5560 | Receiver (both boards) | Active mixer, used as an **upconverter**: 50MHz + 118.2MHz LO -> ~169MHz IF. Replaces the SA612AD. |
| **FSK Receiver** | Si4463-C2A-GM | Receiver (both boards) | Silicon Labs EZRadioPRO, 142-1050MHz, receive-only here. Hardware 2FSK demod, AFC, preamble/sync detect, FIFO, RSSI; ESP32 reads packets over SPI. |
| **LNA** | [SPF5043Z](https://www.qorvo.com/products/p/SPF5043Z) | Front-End | Low-noise amplifier to maximize sensitivity. |

### 3.2 Microcontrollers
- **Ground Station**: **ESP32-S3**. Powerful enough to run the ExpressLRS (ELRS) stack, with integrated WiFi for smartphone configuration and firmware updates.
- **Airplane RX**: **ESP32-S3**. Reads demodulated packets from the Si4463 over SPI and drives the servos; no IF sampling or software demodulation. (The STM32L412 / software-demod plan is superseded.)

---

## 4. Design Specifics

### 4.1 FSK Modulation Technique
The Si5351A is modulated by the MCU updating the `MSx_P1`, `MSx_P2`, and `MSx_P3` registers over I2C.
- **Center Frequency**: 50.800 MHz.
- **Deviation**: ±5 kHz (project standard; older docs said ±2.4 kHz). Must match the Si4463 receiver configuration.
- **Update Rate**: For a 2400 baud link, the registers should be updated at approximately 10kHz to ensure smooth frequency transitions (GFSK).

### 4.2 Receiver Intermediate Frequency (IF)
Both receivers (airplane RX and the ground station's telemetry receiver) use single-conversion **upconversion** into an Si4463, which doesn't tune down to 50MHz (range 142-1050MHz):
- **RF Input**: 50.100 - 51.000 MHz (RC channels 50.800 - 50.980 MHz).
- **Local Oscillator (LO)**: **118.200 MHz, fixed** (Si5351A; RX board CLK0, TX board CLK1, on a separate PLL from the FSK carrier).
- **IF**: IF = RF + LO (sum mixing, no spectral inversion) -> **168.300 - 169.200 MHz** (RC channels at 169.000 - 169.180 MHz).
- **Selectivity**: 3-pole LC band-pass at ~168.75MHz (~3-5MHz BW) rejects LO/RF feedthrough; the Si4463's channel filter provides the narrow selectivity. Image (~287MHz) and the 2xRF-LO response (~143.6MHz) are rejected by the 50MHz BPF.
- **Demodulation**: in the Si4463 (2FSK, AFC enabled -- worst-case frequency error ~6.8kHz exceeds the deviation). Frequency hopping changes the Si4463 channel number; the LO stays fixed.
- **Superseded**: the SA612 / 10.7MHz ceramic filter / MCU DSP plan, and the later CD74HC4046A PLL discriminator. The AX5043 (native 50MHz) was rejected as out of production.

### 4.3 1W Power Amplifier (PA)
The RD01MUS1 requires a simple matching network:
- **Input Match**: Typically a 4:1 or 9:1 transformer to match the low input impedance of the MOSFET.
- **Output Match**: A Pi-network or L-network designed for 50 Ohm load at 50MHz.
- **Low Pass Filter**: A 7-pole Butterworth filter is mandatory to suppress the 100MHz (2nd) and 150MHz (3rd) harmonics to >60dBc.

---

## 5. Antennas
- **Airplane (RX)**: 1.5m (59 inches) 1/4 wave trailing wire. Must be routed away from ESCs, motors, and carbon fiber components.
- **Ground Station (TX)**: 1.5m telescoping whip. For maximum performance, include a 1.5m "tiger tail" counterpoise wire connected to the module ground.

---

## 6. Implementation Notes & Best Practices

> [!IMPORTANT]
> **Licensing**: Operating this system requires a valid Amateur Radio License. Ensure your callsign is programmed into the telemetry data packets to comply with "Automatic Identification" regulations.

> [!WARNING]
> **Thermal Management**: The RD01MUS1 at 1W output is roughly 50-60% efficient, meaning it dissipates ~1W of heat. Use a large ground plane and thermal vias on the PCB to wick heat away.

> [!TIP]
> **Firmware**: Modeling the packet structure after **ExpressLRS (ELRS)** is highly recommended. It provides industry-leading latency and interference rejection.

---

## 7. Verification Plan
1. **Spectral Purity**: Verify harmonic emissions are below -60dBc using a spectrum analyzer.
2. **Frequency Stability**: Test the Si5351A and Si4463 crystals over temperature; confirm the combined carrier + LO + Si4463 XO error stays within the Si4463 AFC pull-in range (trim at build if needed).
3. **Range Test**: Conduct a ground-range test. 1W at 50MHz should provide over 10km of line-of-sight range under ideal conditions.

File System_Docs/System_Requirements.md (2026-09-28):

# Project "Kraft-6M": 50MHz Digital RC Transceiver System
## Overall System Requirements & Project Specification

### 1. Executive Summary
The **Kraft-6M** project is a high-performance "Restomod" of a vintage Kraft 7-channel Series 70 transmitter. The goal is to replace the obsolete 72MHz analog electronics with a modern, high-power (1W) digital GFSK link operating in the **6-meter (50MHz) amateur radio band**. This system provides extreme range, robust obstacle penetration, and full 2-way telemetry while preserving the iconic aesthetic of the original gold Kraft hardware.

---

### 2. General System Specifications
- **Operating Frequency**: 50.0 - 54.0 MHz (Amateur 6m Band).
- **Control Protocol**: Digital GFSK (ExpressLRS-inspired logic).
- **Modulation**: Gaussian Frequency Shift Keying (GFSK).
- **Channels**: 7 proportional channels (16-bit resolution).
- **Telemetry**: 2-way link (RSSI, Battery Voltage, Link Quality).
- **Link Range**: >10 km (Line of Sight, theoretical).

---

### 3. Transmitter (TX) Requirements
The transmitter is housed in a modified Kraft 7 case.

- **Microcontroller**: ESP32-S3 (Dual-core, 16MB Flash).
- **Precision Input**: Dual **ADS1115** 16-bit ADCs for ultra-smooth stick and auxiliary control.
- **RF Modulator**: **Si5351A** Clock Generator (I2C controlled). CLK0 = FSK carrier, CLK1 = 118.2 MHz LO for the telemetry receiver (separate PLLs).
- **Telemetry Receiver**: SPF5043Z LNA + LT5560 upconverter + **Si4463** (same chain as the RX).
- **Power Amplifier (PA)**: **RD01MUS2** MOSFET providing **1.0 Watt (+30 dBm)** output.
- **Filtering**: Mandatory **7-pole Low Pass Filter (LPF)** to suppress harmonics below -50dBc.
- **User Interface**: 1.3" SH1106 OLED display for configuration and telemetry.
- **Power System**: 
    - 2S (7.4V) 2500mAh LiPo battery.
    - Integrated **USB-C Power Delivery (PD)** charging (12V input).
    - Precision buck-regulation (5V) and LDO (3.3V) logic rails.
- **Analog Interface**: JST-XH 2.54mm modular connectors for all stick potentiometers.

---

### 4. Receiver (RX) Requirements
A compact, high-sensitivity receiver for aircraft installation (6m upconverted to a ~169MHz IF and demodulated by an Si4463; revised 2026-09-28, replaces the SDR/software-demod plan).

- **Microcontroller**: ESP32-S3.
- **Front-End (LNA)**: **SPF5043Z** Low Noise Amplifier (<0.8dB Noise Figure).
- **Active Mixer**: **LT5560** active mixer, used as an upconverter (fixed 118.2 MHz LO from the Si5351A).
- **Intermediate Frequency (IF)**: ~169 MHz (168.3 - 169.2 MHz), 3-pole LC band-pass filter.
- **FSK Receiver**: **Si4463-C2A-GM** (receive-only) -- hardware 2FSK demodulation, AFC, sync detect, packet FIFO and RSSI; read by the ESP32-S3 over SPI. The TX's telemetry receiver uses the same chain.
- **Servo Interface**: 8-channel standard 50Hz PWM bus.
- **Power Supply**: 
    - Draws from 5V/6V Servo bus (BEC).
    - **LC Pi-Filter** and **Reverse Polarity Protection** to isolate RF stages from servo noise.
- **Form Factor**: Compact 30x50mm 4-layer PCB.

---

### 5. Firmware & Software Requirements
- **Encoder**: 50Hz frame rate with CRSF-style packet structure.
- **Hopping**: Frequency hopping spread spectrum (FHSS) capability within the 6m band. Receivers hop by Si4463 channel number with a fixed LO.
- **Trim System**: Full digital trim with non-volatile (EEPROM) storage.
- **Fail-Safe**: Programmable "Hold" or "Go-to-Preset" positions upon signal loss.
- **Telemetry Handler**: Real-time CRC8-checked packet decoding for on-screen battery and signal reporting.

---

### 6. Mechanical & Aesthetic Goals
- **Preservation**: No new external holes in the front face of the radio (except the OLED window).
- **Aesthetic**: Use the original mechanical switches and gimbal assemblies.
- **Ergonomics**: Maintain the weight and balance of the original Kraft 7.
- **Durability**: All internal electronics mounted on a rigid "Digital Deck" sub-chassis.

---

### 7. Regulatory Compliance (Ham Radio)
- **License**: Operation requires a valid **Amateur Radio Technician Class** license or higher.
- **Station ID**: Firmware must support periodic station identification (CW or digital) per FCC Part 97.

---
*Document Version: 1.0*
*Project Lead: ne9n*

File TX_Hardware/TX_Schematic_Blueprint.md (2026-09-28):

# 50MHz Transmitter: KiCad Schematic Blueprint

## Visual Schematic Reference
TX Schematic Reference

This document provides a detailed pin-to-pin mapping for the 1W 50MHz transmitter conversion for the Kraft 7 radio.

## 1. Functional Block Diagram

```mermaid
graph LR
    STX[Sticks] --> ADC[ADS1115 16-bit]
    ADC -- I2C --> ESP[ESP32-S3]
    ESP -- I2C --> SI[Si5351A]
    ESP -- I2C --> OLED[SH1106 Display]
    SI -- CLK0 --> PA[RD01MUS2 1W PA]
    PA --> SW[BGS12PL6 T/R Switch]
    SW <--> LPF[7-Pole LPF]
    LPF <--> ANT[Antenna]
    SW -- RX Path --> LNA[SPF5043Z LNA]
    LNA --> MIX[LT5560 Mixer]
    SI -- "CLK1 LO 118.2MHz" --> MIX
    MIX --> IF["169MHz LC IF BPF"]
    IF --> MATCH["AN643 RX Match"]
    MATCH --> SI44["Si4463 FSK Receiver"]
    SI44 -- SPI --> ESP
```

> **Telemetry receiver revised 2026-09-28:** the 10.7MHz IF filter -> ESP32 ADC path is replaced
> by upconversion to a ~169MHz IF (IF = RF + LO, LO fixed at 118.2MHz) and an **Si4463-C2A-GM**
> FSK receiver on SPI. See `RX_Hardware/RX_Design_Details.md` for the rationale and frequency
> plan -- the TX board's telemetry receiver is the same chain as the RX board's. The KiCad
> schematic carries this chain as of 2026-09-28; the PCB is not yet updated (see
> `KiCad_Projects/TX_50MHz_1W/work_instructions.md`).

---

## 2. Component Netlist (Pin-to-Pin)

### 2.1 RF Synthesizer (Modulator)
**IC: Si5351A (MSOP-10)**

| Pin | Name | Connection | Note |
| :--- | :--- | :--- | :--- |
| 1 | VDD | 3.3V | Decouple with 0.1uF |
| 2 | XA | 26MHz Crystal | |
| 3 | XB | 26MHz Crystal | |
| 4 | SCL | ESP32 GPIO 9 | I2C Bus |
| 5 | SDA | ESP32 GPIO 8 | I2C Bus |
| 6 | CLK0 | To PA Input (via 10nF) | RF Drive (FSK carrier, **PLLA**) |
| 7 | CLK1 | To LT5560 Pin 7 (LO+) | **118.200 MHz fixed LO on PLLB** (PLL 709.2MHz, MS /6) |

CLK0 and CLK1 must be on **separate PLLs** so the I2C frequency steps that make the FSK on
CLK0 never disturb the telemetry-receive LO on CLK1.

### 2.2 Power Amplifier (PA)
**IC: RD01MUS2 (SOT-89)**

| Pin | Name | Connection | Note |
| :--- | :--- | :--- | :--- |
| 1 | Gate | From Si5351A CLK0 | Match for 50 Ohm |
| 2 | Source | Ground Plane | Thermal Tab |
| 3 | Drain | To Switch RF1 (via RFC) | Power feed 7.2V-9.6V |

### 2.3 RF T/R Switch
**IC: BGS12PL6 (TSLP-6)**

| Pin | Name | Connection | Note |
| :--- | :--- | :--- | :--- |
| 1 | RF2 | To Telemetry LNA Input | RX Path (Telemetry) |
| 2 | GND | Ground Plane | |
| 3 | RF1 | From PA Output (Drain) | TX Path (Control) |
| 4 | CTRL | ESP32 GPIO (TR_SW) | High = TX, Low = RX |
| 5 | ANT | To LPF Input | Shared Port |
| 6 | VDD | 3.3V Rail | Decouple with 0.1uF |

### 2.4 Telemetry Receiver Stage
**ICs: SPF5043Z (LNA) & LT5560 (Mixer)**

| Stage | Component | Connection | Note |
| :--- | :--- | :--- | :--- |
| **LNA In** | SPF5043Z Pin 1| From Switch RF2 | 50MHz Input |
| **Mixer RF**| LT5560 Pin 1 | From LNA Output | |
| **Mixer LO**| LT5560 Pin 7 | From Si5351A CLK1 | Local Oscillator, 118.2MHz fixed |
| **Mixer IF**| LT5560 Pin 5 | To 169MHz IF BPF | IF = RF + LO (168.3-169.2MHz); output network tuned for 169MHz, both outputs need a DC path to VCC |
| **IF BPF** | 3-pole LC | To Si4463 RX match | Centre ~168.75MHz, ~3-5MHz BW, 50 Ohm; values TBD (SPICE) |
| **RX Match** | AN643 network | To Si4463 RXp/RXn | Single-ended -> differential LNA match, 169MHz values |
| **Receiver** | Si4463 | SPI to ESP32 | Replaces the 10.7MHz SFE filter (FL1) -> ESP32 ADC (IO10 `ADC_IN`) path |

Frequency hopping on receive is done by the Si4463 channel number; the LO stays fixed.

### 2.4a Telemetry FSK Receiver
**IC: Si4463-C2A-GM (QFN-20 4x4mm + EP)** -- KiCad `RF:Si4463`, footprint
`Package_DFN_QFN:QFN-20-1EP_4x4mm_P0.5mm_EP2.6x2.6mm_ThermalVias`. Receive-only.

| Pin | Name | Connection | Note |
| :--- | :--- | :--- | :--- |
| 1 | SDN | ESP32 GPIO 17 (SI_SDN) | High = shutdown; drive low to run |
| 2 | RXp | From IF BPF via AN643 match | |
| 3 | RXn | From IF BPF via AN643 match | |
| 4 | TX | Not Connected | Receive-only, never enter TX state |
| 5 | NC | Not Connected | |
| 6, 8 | VDD | 3.3V Rail | 100nF + 1uF each (+10pF at pin 8) |
| 7 | TXRAMP | Not Connected | |
| 9 | GPIO0 | Test point (optional RX_STATE) | |
| 10 | GPIO1 | Optional CTS | Can poll CTS over SPI instead |
| 11 | nIRQ | ESP32 GPIO 16 (SI_nIRQ) | Open-drain, 10k pull-up to 3.3V |
| 12 | SCLK | ESP32 GPIO 12 | SPI SCK (GPIO matrix), <=10MHz, mode 0 |
| 13 | SDO | ESP32 GPIO 14 | SPI MISO |
| 14 | SDI | ESP32 GPIO 13 | SPI MOSI |
| 15 | nSEL | ESP32 GPIO 15 | SPI CS |
| 16, 17 | XOUT, XIN | 30.000MHz Crystal | Internal tunable load caps; no external caps |
| 18, EP | GND | Ground Plane | Via-stitch the exposed pad |

TX-board SPI pins are **proposed** (IO10 = old `ADC_IN`, IO11 = T/R switch CTRL are taken by the
current netlist; IO10 is freed once the ADC path is removed) -- confirm against the schematic.

### 2.5 Precision ADC (Main Sticks)
**IC: ADS1115 (VSSOP-10) - Address 0x48**

| Pin | Name | Connection | Note |
| :--- | :--- | :--- | :--- |
| 1 | ADDR | GND | Sets I2C Address 0x48 |
| 4 | AIN0 | [J1] Pin 2 | Aileron Wiper |
| 5 | AIN1 | [J2] Pin 2 | Elevator Wiper |
| 6 | AIN2 | [J3] Pin 2 | Throttle Wiper |
| 7 | AIN3 | [J4] Pin 2 | Rudder Wiper |
| 8 | VDD | 3.3V | |

### 2.6 Precision ADC (Aux Channels)
**IC: ADS1115 (VSSOP-10) - Address 0x49**

| Pin | Name | Connection | Note |
| :--- | :--- | :--- | :--- |
| 1 | ADDR | VDD | Sets I2C Address 0x49 |
| 4 | AIN0 | [J5] Pin 2 | Aux Channel 5 |
| 5 | AIN1 | [J6] Pin 2 | Aux Channel 6 |
| 6 | AIN2 | [J7] Pin 2 | Aux Channel 7 |
| 7 | AIN3 | Voltage Divider | Battery Monitoring |

### 2.7 Analog Connectors (J1 - J7)
**Type: 3-Pin JST-XH 2.54mm**

| Pin | Name | Connection |
| :--- | :--- | :--- |
| 1 | VCC | 3.3V Analog Bus |
| 2 | Wiper | To ADC AINx |
| 3 | GND | Analog Ground |

### 2.8 Power & Utility Connectors (J8 - J10)

**J8: Battery Input (2-Pin JST-VH or XT30)**
| Pin | Name | Connection | Note |
| :--- | :--- | :--- | :--- |
| 1 | V_BATT | From Kraft Power Switch | 7.4V - 9.6V |
| 2 | GND | System Ground | |

**J9: 5V Logic Power (2-Pin JST-XH)**
| Pin | Name | Connection | Note |
| :--- | :--- | :--- | :--- |
| 1 | 5V_IN | From Buck Converter Out | Powers ESP32 Vin |
| 2 | GND | System Ground | |

**J10: I2C Expansion / OLED (4-Pin JST-XH)**
| Pin | Name | Connection | Note |
| :--- | :--- | :--- | :--- |
| 1 | VCC | 3.3V Logic | |
| 2 | GND | Ground | |
| 3 | SCL | ESP32 GPIO 9 | |
| 4 | SDA | ESP32 GPIO 8 | |

---

## 3. Power Amplifier Biasing & Matching

### 3.1 Input Matching (Si5351A to RD01)
- **C1**: 10 nF (DC Block)
- **L1**: 150 nH (Series Inductor for Gate Match)

### 3.2 Output Matching & LPF
- **RFC**: 1.0 uH (0805 Power Inductor to V_BATT)
- **7-Pole LPF (50MHz Cutoff)**:
    - **C values**: 120pF, 220pF, 220pF, 120pF.
    - **L values**: 180nH, 180nH, 180nH.

---

## 4. Power Rails

| Net Name | Voltage | Source | Destination |
| :--- | :--- | :--- | :--- |
| **V_BATT** | 7.4V - 9.6V | 2S/3S LiPo | PA Drain (RFC) |
| **5V** | 5.0V | Buck Converter | ESP32 Vin |
| **3.3V** | 3.3V | ESP32 Regulator | ADS1115, OLED, Si5351A, LT5560, Si4463 |

---
*Created for the Kraft 7 "Restomod" Project.*

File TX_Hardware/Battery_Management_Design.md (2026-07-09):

# Kraft 7: Battery Management & LiPo Conversion

This document details the conversion of the vintage Kraft 7 transmitter from NiCd batteries to a modern, safe LiPo system with USB-C charging.

## 1. System Requirements
- **Input Voltage**: 7.4V (2S LiPo) or 11.1V (3S LiPo). *Note: The RD01MUS2 PA performs best at 7.2V - 9.0V.*
- **Charging**: Integrated USB-C charging (no need to open the case).
- **Protection**: Low-voltage cutoff to prevent LiPo damage.

---

## 2. Proposed Power Architecture

```mermaid
graph LR
    USB[USB-C Port] --> CHG[TP5100 2S Charger]
    CHG --> BATT[2S 2500mAh LiPo]
    BATT --> SW[Original Kraft Power Switch]
    SW --> BUCK[MP1584EN 5V Buck]
    BUCK --> ESP[ESP32-S3 & Logic]
    SW --> PA[1W Power Amplifier]
```

---

## 3. Component Selection

| Component | Part Number | Function |
| :--- | :--- | :--- |
| **Battery** | 2S 7.4V LiPo (Flat) | Fits in the original battery compartment. |
| **Charger IC** | **TP5100** | Supports 2S (8.4V) charging from a 12V input. |
| **USB-C Input** | **USB-C Sink PD** | Trigger 12V from a modern USB-C PD brick. |
| **Protection IC**| **HY2120** | 2-Cell Li-ion protection (Overcharge/Over-discharge). |
| **Buck Regulator**| **MP1584EN** | High-efficiency 5V supply for the ESP32. |

---

## 4. Implementation Steps

### 4.1 Safe Charging
- Use a **USB-C PD Trigger board** set to **12V**. This allows you to use standard phone/laptop chargers to charge the radio.
- Feed the 12V into the **TP5100** charger module configured for **2S (8.4V)**.

### 4.2 Voltage Monitoring
- Connect the LiPo (+) through a 100k/10k resistor divider to the **ESP32 GPIO 4**.
- **Firmware**: Program the OLED to display a battery percentage and sound an alarm (piezo) if voltage drops below **6.8V** (3.4V per cell).

### 4.3 Mechanical Integration
- Mount the USB-C port in the original charging jack hole of the Kraft case.
- Ensure the LiPo is securely padded with foam to prevent movement inside the metal case.

---

## 5. Wiring Diagram Summary
1.  **LiPo (+)** -> Protection Board -> Kraft Switch -> PA Drain & Buck Input.
2.  **LiPo (-)** -> Protection Board -> System GND.
3.  **ESP32 3.3V** -> ADS1115 VDD (For stable ADC reference).

---
*Safety Warning: Always use a protected LiPo cell and never leave charging batteries unattended inside a metal case.*

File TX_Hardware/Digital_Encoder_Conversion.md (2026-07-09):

# Digital Encoder Conversion (Kraft 7 Restomod)

This guide details how to replace the legacy analog electronics of a Kraft 7 transmitter with a modern, high-precision digital encoder based on the **ESP32**.

## 1. Concept
We strip out the original Kraft encoder board but keep the high-quality aluminum stick gimbals and the case. The ESP32 becomes the "brain," reading the stick positions digitally and driving the 50MHz RF deck.

## 2. Hardware Architecture

### 2.1 Stick Input (High Precision)
The original Kraft sticks use 5k or 10k potentiometers. While the ESP32 has internal ADCs, they are often too noisy for smooth RC control.
- **Recommended ADC**: **ADS1115** (16-bit I2C ADC).
- **Wiring**:
  - Connect the top and bottom of all stick pots to the ESP32's **3.3V** and **GND**.
  - Connect the center wipers of the 4 main axes (Ail, Ele, Thr, Rud) to the ADS1115 inputs (A0-A3).
  - Connect the remaining 3 auxiliary channels to the ESP32's internal ADC pins (GPIO 32-34).

### 2.2 User Interface (OLED Display)
To make the transmitter truly modern, add a small display:
- **Part**: 1.3" I2C OLED (SH1106 or SSD1306).
- **Features**:
  - Live Telemetry (Airplane battery, Signal strength).
  - Stick Calibration menu.
  - Model Memory (Store settings for multiple planes).

---

## 3. Wiring Diagram

```mermaid
graph TD
    subgraph "Kraft Sticks & Switches"
        Sticks["4x Main Pots (5k)"]
        Aux["3x Aux Pots/Switches"]
    end

    subgraph "Encoder Core"
        ADC["ADS1115 (16-bit ADC)"]
        ESP["ESP32-S3"]
        Disp["OLED Display (I2C)"]
    end

    subgraph "50MHz RF Deck"
        RF["Si5351A + 1W PA"]
    end

    Sticks --> ADC
    Aux --> ESP
    ADC -- "I2C" --> ESP
    Disp -- "I2C" --> ESP
    ESP -- "I2C" --> RF
```

---

## 4. Software Features (Firmware)

### 4.1 Calibration & Deadband
Digital sticks require a calibration routine to find the physical center and endpoints.
- **Deadband**: Small software buffer at the center (e.g., ±10 units) to prevent "servo jitter" when hands are off the sticks.

### 4.2 Exponential & Dual Rates
Implement modern flight feel:
- **Expo**: Softens the center of the sticks for smoother flying.
- **Dual Rates**: Toggle switch to reduce maximum throw for beginners or high-speed flight.

### 4.3 Telemetry Feedback
Since the link is 2-way, the ESP32 will receive telemetry packets from the airplane 50MHz receiver and update the OLED display in real-time.

---

## 5. Implementation Steps
1. **Gut the Kraft**: Remove the old PCB and wiring, leaving only the pots and the battery box.
2. **Mount the ESP32**: Use the space where the old RF deck sat.
3. **Wire the Pots**: Ensure clean, shielded wiring for the analog signals to prevent interference from the 1W PA.
4. **Flash Firmware**: Use the ExpressLRS-based logic adapted for the ADS1115 input.

---
*Note: This conversion turns a 50-year-old radio into a state-of-the-art digital 6-meter system.*

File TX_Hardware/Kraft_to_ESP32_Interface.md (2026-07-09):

# Kraft 7 Transmitter to ESP32 Interface

This guide describes how to connect a vintage Kraft 7-channel transmitter to a modern ESP32-based 50MHz transceiver deck.

## 1. Interface Requirements
- **Kraft Signal**: Analog PPM (Pulse Position Modulation).
- **ESP32 Input**: GPIO 4 (Interrupt-enabled).
- **Logic Level**: 3.3V (Requires level shifting from Kraft's 5V-9V signal).

## 2. Hardware Connections

### 2.1 Level Shifting (Kraft to ESP32)
Since the Kraft encoder may output signals up to 9.6V, a simple voltage divider is required to protect the ESP32:
- **R1 (Series)**: 22k Ohm.
- **R2 (Shunt to GND)**: 10k Ohm.
- **Output**: This provides ~3.0V from a 9.6V source, safe for the ESP32.

### 2.2 Power Supply
- Use a small **Step-down (Buck) Converter** to drop the Kraft's 9.6V-12V battery voltage to **5V** for the ESP32.
- The ESP32's on-board regulator will provide the **3.3V** needed for the Si5351A.

## 3. Firmware Logic (PPM Decoding)

The ESP32 must accurately measure the pulse widths from the Kraft encoder.

### Example PPM Decoder Snippet
```cpp
volatile uint32_t channel_values[8];
volatile uint32_t last_time = 0;
volatile uint8_t current_channel = 0;

void IRAM_ATTR ppm_interrupt() {
    uint32_t now = micros();
    uint32_t duration = now - last_time;
    last_time = now;

    if (duration > 3000) { // Sync Pulse detected
        current_channel = 0;
    } else {
        if (current_channel < 8) {
            channel_values[current_channel] = duration;
            current_channel++;
        }
    }
}

void setup() {
    pinMode(4, INPUT_PULLDOWN);
    attachInterrupt(4, ppm_interrupt, RISING);
}
```

## 4. Signal Integration
1. **Decode**: ESP32 reads 7 channels from the Kraft sticks.
2. **Packetize**: Encapsulate the 7 channels into a digital packet with CRC.
3. **Transmit**: Send the packet via the 50MHz Si5351A RF stage.

---
*Note: Ensure the Kraft internal RF section is disconnected or the crystal is removed to prevent interference and save battery power.*

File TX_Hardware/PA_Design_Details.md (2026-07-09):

# RD01MUS1 1W Power Amplifier Design (50MHz)

This document provides a detailed technical description of the **1 Watt RF Power Amplifier (PA)** stage for the 6m (50MHz) ground station transceiver.

## 1. Core Component: RD01MUS1
The **RD01MUS1** is a Silicon MOSFET designed for VHF/UHF power amplification.
- **Package**: SOT-89 (Small Outline Transistor).
- **Drain-Source Voltage ($V_{DSS}$)**: 30V Max.
- **Output Power ($P_{out}$)**: Typical 0.8W - 1.2W at 7.2V.
- **Gain**: ~14dB at 50MHz (High gain, requires stable biasing).

---

## 2. Schematic Topology

The PA follows a standard Class AB configuration for a balance between linearity (important for GFSK) and efficiency.

### 2.1 Input Matching Network
The input impedance of the RD01MUS1 at 50MHz is low and primarily capacitive.
- **Topology**: L-Match or a 4:1 Broadband Transformer (Binocular Core).
- **Components**: 
    - Series Inductor: ~47nH.
    - Shunt Capacitor: ~82pF.
- **Goal**: Transform the 50 Ohm input from the Si5351A/Buffer to the ~5-10 Ohm gate impedance.

### 2.2 Biasing Circuit
- **Gate Bias ($V_{GS}$)**: A stable 2.0V - 3.0V is required to set the quiescent current ($I_{DQ}$) to roughly 50-100mA.
- **Implementation**: Use a multi-turn trimmer potentiometer connected to a 5V regulated rail, decoupled with a 10uF tantalum and 100nF ceramic capacitor.

### 2.3 Output Matching & DC Feed
- **DC Feed (RFC)**: A 1.0uH RF Choke (high current rated) supplies 7.2V to the Drain.
- **Output Match**: Pi-Network.
    - $C_1$: 33pF.
    - $L$: 120nH.
    - $C_2$: 27pF.
- **Goal**: Transform the Drain impedance to the 50 Ohm load.

---

## 3. Harmonic Suppression (LPF)

Because 1W is significant power, a **7-pole Low Pass Filter** is required to keep the signal within Amateur Radio spectral limits.
- **Cutoff Frequency ($f_c$)**: 55 MHz.
- **Rejection**: >60dB at 100MHz (2nd harmonic) and 150MHz (3rd harmonic).
- **Topology**: C-L-C-L-C-L-C (Butterworth).

---

## 4. Thermal & PCB Layout Guidelines

> [!IMPORTANT]
> **Thermal Vias**: The SOT-89 package dissipates heat through the **Source tab (Pin 2)**. You MUST place at least 9-16 small thermal vias (0.3mm) directly under this tab, connecting it to a large bottom-side ground plane.

> [!WARNING]
> **Stability**: VHF amplifiers can easily oscillate. Keep all traces as short as possible. Use a solid, unbroken ground plane under the entire PA section.

### Layout Checklist:
1. **Input/Output Isolation**: Keep the input matching components physically separated from the output matching to prevent feedback loops.
2. **Decoupling**: Place the 100nF and 1nF bypass capacitors as close as possible to the RFC and Gate bias pins.
3. **Copper Weight**: Use 1oz or 2oz copper to handle the ~300mA current and improve thermal spread.

---

## 5. Performance Targets
- **Input Power**: +10dBm (10mW).
- **Output Power**: +30dBm (1.0W).
- **Efficiency**: 45% - 55%.
- **Operating Voltage**: 6.0V - 8.4V (2S LiPo compatible).

---
*Reference: Mitsubishi RD01MUS1 Datasheet & VHF RF Design Principles.*

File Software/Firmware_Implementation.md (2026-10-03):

# Firmware Implementation Guide (50MHz FSK)

This document provides example code and logic for implementing FSK modulation on the Si5351A and packet reception on the ESP32-S3 via an **Si4463** FSK receiver (both the RX board and the TX board's telemetry receiver).

## 1. Si5351A FSK Modulation (Transmitter)

The Si5351A does not have a native "FSK" pin. We achieve modulation by rapidly updating the frequency registers over I2C.

### Deferred issue: complete and verify TX FSK
- [ ] Fix the deviation units in `Si5351_GFSK_Driver.cpp` (currently ±500 kHz instead of the documented ±5 kHz), implement packet transmission in `transmitFrame()` including preamble/sync/CRC, and decide whether Gaussian shaping is required; the current bit switching is 2FSK, not GFSK.

### Example Code (C++/Arduino)
```cpp
#include <si5351.h>
#include <Wire.h>

Si5351 si5351;

// Frequencies for 50.800 MHz RC Window
const uint64_t center_freq = 5080000000ULL; // in 0.01Hz units
const uint32_t fsk_deviation = 500000;      // 5kHz deviation (+-5kHz, project standard;
                                            // older docs said 2.4kHz -- the Si4463 receiver
                                            // is configured for +-5kHz, keep them matched)

void setup() {
  si5351.init(SI5351_CRYSTAL_LOAD_8PF, 0, 0);
  // CLK0 (FSK carrier) on PLLA, CLK1 (118.2MHz receive LO) on PLLB -- separate PLLs so
  // the per-bit FSK updates to CLK0 never disturb the LO.
  si5351.set_ms_source(SI5351_CLK0, SI5351_PLLA);
  si5351.set_ms_source(SI5351_CLK1, SI5351_PLLB);
  si5351.set_freq(center_freq, SI5351_CLK0);
  si5351.set_freq(11820000000ULL, SI5351_CLK1); // 118.200MHz LO, fixed
}

// Function to send a single bit (Very simplified)
void sendBit(bool bit) {
  uint64_t target_freq = bit ? (center_freq + fsk_deviation) : (center_freq - fsk_deviation);
  
  // Directly update the Multisynth frequency registers
  // In a real ELRS-like implementation, use a high-speed I2C library
  si5351.set_freq(target_freq, SI5351_CLK0);
}

void loop() {
  // Example bitstream
  sendBit(1); delayMicroseconds(416); // 2400 baud
  sendBit(0); delayMicroseconds(416);
}
```

### Advanced Implementation: GFSK
To implement **Gaussian** FSK (GFSK), instead of jumping directly between `Freq+Shift` and `Freq-Shift`, the MCU should ramp the frequency using a lookup table (SINE or GAUSSIAN) to smooth the transitions. This significantly reduces occupied bandwidth.

---

## 2. Receiver Demodulation

**Current architecture (use this): Si4463 packet receiver over SPI.**
The 6m signal is upconverted by the LT5560 mixer (Si5351A LO fixed at 118.200MHz,
IF = RF + LO, so 50.1-51.0MHz lands at 168.3-169.2MHz with no spectral inversion) and
demodulated by an **Si4463-C2A-GM** in hardware. The ESP32 never sees analog IF or baseband
-- it reads finished packets over SPI (<=10MHz, mode 0). Same code on the RX board and on the
TX board's telemetry receiver. Receive flow:
1. **Power-up**: drive SDN low, wait for POR, send the WDS / Simplicity Studio Radio
   Configurator output (`radio_config_si4463.h`: POWER_UP + properties) over SPI, polling CTS
   between commands. AFC enabled (worst-case frequency error ~6.8kHz exceeds the +-5kHz
   deviation).
2. **START_RX** on channel N (current hop), fixed packet length (22-byte payload after sync).
3. **nIRQ on PACKET_RX** -> read 22 bytes from the RX FIFO, read the latched RSSI
   (FRR or GET_MODEM_STATUS) -> check CRC8 (poly 0x07) **in firmware** (Si4463 hardware CRC
   disabled) -> update servos (RX board) / telemetry display (TX board).
4. **Hop timer**: START_RX with the next channel number. The LO stays fixed -- no Si5351
   retune or I2C traffic on the receive side per hop.
5. **Failsafe** unchanged: 500ms without a valid packet -> neutral/preset.
6. **RSSI** for the telemetry RSSI / link-quality fields now comes from the Si4463.

Suggested files: `si4463_radio.h/.cpp` (SPI driver: CTS poll, command/response, FIFO read,
START_RX) and `radio_config_si4463.h` (WDS output). Pin map and hardware details:
`RX_Hardware/RX_Design_Details.md` and `RX_Hardware/RX_Schematic_Blueprint.md`.

**Superseded (kept for reference, do not use): CD74HC4046A PLL discriminator.**
`fsk_baseband_slicer.h`, `RX_FSK_Demod_PLL.ino` and `test/fsk_baseband_slicer_selftest.cpp`
implement a baseband bit slicer behind a 4046 PLL demodulating the 10.7MHz IF. Dropped
because the HC4046 VCO is marginal/out of spec at 10.7MHz on 3.3V, and it is demod-only (no
AFC, RSSI, sync detect or packet handling), leaving all of that to firmware.

**Superseded (kept for reference, do not use): IF-undersampling.**
`fsk_demod_core.h`, `RX_FSK_Demod.ino` and `test/fsk_demod_selftest.cpp` sample the raw
10.7MHz IF with the ADC and demodulate in software. The algorithm is verified, but the
ESP32-S3 ADC is capped at 83,333 Hz (`SOC_ADC_SAMPLE_FREQ_THRES_HIGH`), far too slow for the
~230kHz-wide 10.7MHz ceramic filter output.

---

## 3. Packet Structure (ELRS Compatible)

To ensure reliability, use a packet structure similar to ExpressLRS:
- **Preamble**: at least 5 bytes (40 bits) of alternating `0x55`/`0xAA` so the Si4463's AFC and preamble detector settle.
- **Sync Word**: `0x1D4A` (2 bytes), detected by the Si4463 packet handler.
- **Payload**: Control channels (AIL, ELE, THR, RUD) + Telemetry, fixed length.
- **CRC**: CRC8 (poly 0x07) computed and checked in firmware (see `Firmware_Protocol_Spec.md`); Si4463 hardware CRC disabled.
- **Encoding**: NRZ, no whitening. The Si4463 can't decode 8b/10b; hardware Manchester is the fallback if long runs cause bit errors.

---
*Note: High-speed I2C (400kHz or 1MHz) is mandatory for the Si5351A to support baud rates above 1200 bps.*

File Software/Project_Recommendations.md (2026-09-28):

# Recommended Open Source Projects for Kraft 7 Digital

To accelerate the development of the Kraft 7 restomod, it is recommended to draw from these established open-source projects.

## 1. Encoder Project: SimpleTX
**Goal**: Handle stick reading, OLED menus, and model memory.

SimpleTX is an Arduino-based framework for DIY radio transmitters. It is highly modular and suitable for the ESP32.
- **Repository**: [https://github.com/m-reuter/SimpleTX](https://github.com/m-reuter/SimpleTX)
- **Key Features for Kraft**:
    - ADS1115 ADC support.
    - Multi-model memory.
    - Graphical OLED status screens.
    - Calibration routines for old potentiometers.

## 2. Link Project: ExpressLRS (ELRS)
**Goal**: Provide a robust, long-range digital link at 50MHz.

ExpressLRS is the industry standard for high-performance RC links. While primarily used at 2.4GHz/915MHz, the **Protocol Logic** and **CRSF Serial Format** are perfect for this project.
- **Repository**: [https://github.com/ExpressLRS/ExpressLRS](https://github.com/ExpressLRS/ExpressLRS)
- **Application for 50MHz**:
    - Use the **CRSF Protocol** to pass data between the Encoder task and the RF task.
    - Adapt the ELRS **Packet Framing** (Preamble, Sync, Payload, CRC) for the Si5351A FSK modulation, within what the **Si4463** receiver's packet handler can decode (>=5-byte `0x55` preamble, `0x1D4A` sync, NRZ, fixed length -- see `Firmware_Protocol_Spec.md`).
    - Leverage ELRS **Telemetry** code to display airplane battery voltage on the Kraft's OLED.

## 3. Recommended Workflow
1. **Fork SimpleTX**: Adapt it to run on the ESP32-S3 and read the 16-bit ADS1115.
2. **Integrate CRSF**: Configure SimpleTX to output a 420kbaud CRSF serial stream internally.
3. **RF Driver**: Write a dedicated task that listens to the CRSF stream and bit-bangs the Si5351A frequency registers at 50.8MHz, and receives telemetry from the Si4463 over SPI (`si4463_radio.h`).

---
*Reference: Open source RC development community.*

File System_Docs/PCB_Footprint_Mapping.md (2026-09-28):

# Kraft-6M: KiCad PCB Footprint Mapping

This document maps the BOM components to the exact KiCad library footprint names to simplify the board layout process.

## 1. Transmitter (TX) Footprints

| Component | KiCad Library Footprint | Note |
| :--- | :--- | :--- |
| **ESP32-S3-WROOM-1** | `RF_Module:ESP32-S3-WROOM-1-N8` | Standard Espressif Module |
| **Si5351A-B-GT** | `Package_SO:MSOP-10_3x3mm_P0.5mm` | 10-pin MSOP |
| **RD01MUS2** | `Kraft6M:RD01MUS2` | Center pad is RF Ground/Heat Sink |
| **ADS1115IDGSR** | `Kraft6M:ADS1115` | |
| **1.3" OLED (SH1106)** | `Connector_PinHeader_2.54mm:PinHeader_1x04_P2.54mm_Vertical` | 4-pin I2C header |
| **26MHz Crystal** | `Crystal:Crystal_SMD_3225-4Pin_3.2x2.5mm` | Standard 3.2x2.5mm SMD |
| **Inductors (180nH)** | `Kraft6M:L_180nH_0805` | Specific for 50MHz LPF |
| **Capacitors (120/220pF)**| `Kraft6M:C_120pF_0805` / `C_220pF_0805` | Specific for 50MHz LPF |
| **RF Choke (1.0uH)** | `Kraft6M:L_1.0uH_1206` | High-current bias tee |
| **SMA (Edge Mount)** | `Connector_Coaxial:SMA_Amphenol_132289_EdgeMount` | For 1.6mm PCB |
| **JST-XH (3-pin)** | `Connector_JST:JST_XH_B3B-XH-A_1x03_P2.50mm_Vertical` | |

---

## 2. Receiver (RX) Footprints

| Component | KiCad Library Footprint | Note |
| :--- | :--- | :--- |
| **ESP32-S3-WROOM-1** | `RF_Module:ESP32-S3-WROOM-1-N8` | |
| **LT5560 Mixer** | `Kraft6M:LT5560` | 2x2mm DFN-8 |
| **SPF5043Z LNA** | `Kraft6M:SPF5043Z` | |
| **IF Filter (10.7MHz)**| `Kraft6M:SFE10.7` | Superseded -- removed (replaced by the ~169MHz LC BPF) |
| **Si4463-C2A-GM** | `Package_DFN_QFN:QFN-20-1EP_4x4mm_P0.5mm_EP2.6x2.6mm_ThermalVias` | Symbol `RF:Si4463`; also on the TX board (telemetry RX) |
| **30MHz Crystal (Si4463)** | `Crystal:Crystal_SMD_3225-4Pin_3.2x2.5mm` | Si4463 reference |
| **IF BPF / RX Match** | 0603 L/C (C0G) | ~169MHz LC BPF + AN643 match; values TBD |
| **AP2112K-3.3** | `Package_TO_SOT_SMD:SOT-23-5` | |
| **Inductors (Match)** | `Kraft6M:L_220nH_0603` | Specific for LNA match |
| **Capacitors (Match)** | `Kraft6M:C_100pF_0603` | Specific for RF path |
| **Bulk Cap (470uF)** | `Kraft6M:C_470uF_Radial` | Electrolytic |
| **SS14 Diode** | `Diode_SMD:D_SMA` | |
| **Servo Headers** | `Connector_PinHeader_2.54mm:PinHeader_1x03_P2.54mm_Vertical` | |

---

## 3. General Passive Sizes
*   **0805 (2012 Metric)**: Used for TX Power/Filter stages for higher power handling.
*   **0603 (1608 Metric)**: Used for RX signal path to minimize parasitic inductance.
*   **C0G/NP0**: Ensure all RF capacitors (LPF/Matching) are C0G/NP0 dielectric for frequency stability.

*Created for the Kraft-6M Project.*

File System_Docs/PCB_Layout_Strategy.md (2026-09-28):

# PCB Layout Strategy (50MHz RF Design)

Designing a 50MHz transceiver requires careful attention to grounding, isolation, and thermal management to achieve the 1W output target while maintaining receiver sensitivity.

## 1. Stackup Recommendation
- **4-Layer PCB** is highly recommended.
  - **Layer 1 (Top)**: Signal, RF traces, and components.
  - **Layer 2**: Solid Ground Plane (Critical for RF return paths).
  - **Layer 3**: Power Rails (7.2V PA, 3.3V Digital).
  - **Layer 4 (Bottom)**: Solid Ground Plane and non-critical signals.

---

## 2. RF Grounding & Isolation
- **Solid Ground Plane**: Do not split the ground plane. Use a single, continuous plane on Layer 2 to provide the lowest possible impedance for RF return currents.
- **Vias**: Use "Via Stitching" around the edge of the board and between RF sections to connect the Top and Bottom ground pours.
- **Isolation**: Keep the **TX PA section** physically separated from the **RX LNA section**. The T/R switch should be the only point where they meet.

---

## 3. Power Amplifier (PA) Layout
- **Thermal Vias**: The RD01MUS2 dissipates heat through the Source tab. Place a 4x4 grid of 0.3mm thermal vias directly under the tab.
- **Output Trace**: The trace from the PA to the LPF and Antenna should be **50 Ohm Impedance Controlled**. On a standard 1.6mm FR4 4-layer board, this is typically ~0.3mm to 0.5mm wide (verify with your fab's stackup).
- **Decoupling**: Place 10uF and 100nF capacitors as close as possible to the Drain DC feed (RFC).

---

## 4. Receiver (RX) Layout
- **LNA Proximity**: The SPF5043Z LNA should be placed as close as possible to the RF Switch/Antenna connector.
- **Shielding**: If possible, leave space for a small SMD "Shield Can" over the LNA and Mixer stage to prevent pickup of noise from the MCU or ESCs.
- **IF Section (~169MHz)**: Keep the LT5560 output -> LC BPF -> Si4463 match path short and compact, ideally under the same shield can. 169MHz is not a quiet band (land-mobile/paging nearby), so direct pickup on the IF traces is a layout risk; the 50MHz BPF can't reject it.
- **Si4463**: 30MHz crystal right next to XIN/XOUT, EP stitched to ground, decoupling at both VDD pins. Keep the SPI lines away from the RF/IF path. Applies to both boards (the TX has the same telemetry receiver).

---

## 5. Digital Noise Reduction
- **Clock Generators**: Keep the Si5351A and its 26MHz crystal far away from the LNA input. The 118.2MHz LO trace to the LT5560 should be short and away from the IF band-pass filter.
- **I2C Routing**: Route the I2C lines (SDA/SCL) away from the RF path. Use 10k pull-ups and consider adding small 47pF capacitors if digital noise is visible in the RX floor.

---

## 6. Antenna Connector
- **Type**: Use an **SMA** or **BNC** connector for the Ground Station. Use a simple through-hole solder pad for the 1.5m wire on the Airplane RX.
- **Grounding**: Ensure the connector ground tabs are soldered to both the top and bottom planes with multiple vias.

---
*Reference: High-Speed Digital & RF Design Principles (Henry Ott / Howard Johnson).*

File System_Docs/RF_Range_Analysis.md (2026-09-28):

# 50MHz 1W RC Link: RF Range & Link Budget Analysis

This document provides a theoretical analysis of the expected range and reliability for the 1W 50MHz RC system.

## 1. System Parameters

| Parameter | Value | Note |
| :--- | :--- | :--- |
| **Transmit Power (Pt)** | +30 dBm (1 Watt) | Output after LPF |
| **Transmit Antenna Gain (Gt)** | 2.15 dBi | Standard half-wave whip |
| **Receive Antenna Gain (Gr)** | -3.0 dBi | Shortened wire antenna (compromised) |
| **Receiver Sensitivity (Pr)** | -105 dBm | Conservative planning figure for SPF5043Z LNA + LT5560 upconverter + Si4463 receiver (169MHz IF). Keep until measured; Si4463 sensitivity per datasheet, TBD |
| **Operating Frequency** | 50.1 MHz | 6-meter Ham Band |

---

## 2. Link Budget Calculation

### 2.1 Free Space Path Loss (FSPL)
At 50MHz, the wavelength ($\lambda$) is approximately **6.0 meters**.

**Formula**: $FSPL (dB) = 20 \log_{10}(d) + 20 \log_{10}(f) - 147.55$
*(Where d is in meters, f is in Hz)*

### 2.2 Range Estimates (Visual Line of Sight)

| Distance | Path Loss (50MHz) | Fade Margin | Link Status |
| :--- | :--- | :--- | :--- |
| **500 m** | 60.4 dB | 76.7 dB | Solid |
| **1.0 km**| 66.4 dB | 70.7 dB | Solid |
| **5.0 km**| 80.4 dB | 56.7 dB | Reliable |
| **10.0 km**| 86.4 dB | 50.7 dB | Very High Reliability |

**Theoretically, 1W at 50MHz is capable of 20km+ range** if both antennas have clear line-of-sight. For RC model use, the range will be limited by the pilot's vision long before the signal fails.

---

## 3. Advantages of 50MHz over 2.4GHz
1.  **Fresnel Zone Clearance**: 50MHz has a much larger first Fresnel zone, meaning it is less affected by ground reflections at low altitudes.
2.  **Obstacle Penetration**: 6-meter signals wrap around hills, buildings, and trees much better than 2.4GHz microwave signals.
3.  **Ground Effect**: 2.4GHz signals are heavily absorbed by wet grass and soil; 50MHz is far more resilient for low-altitude flying.

---

## 4. Potential Risks & Interference
- **Man-Made Noise**: 50MHz can be susceptible to noise from electric motors and high-power switching supplies.
- **Atmospheric Conditions**: During periods of high solar activity (Sporadic-E), 50MHz can "skip" over the horizon, potentially causing interference from stations hundreds of miles away.
- **Harmonics**: 1W is significant power. The **7-pole Low Pass Filter** is mandatory to prevent interference with television and public safety bands.

---

## 5. Conclusion
With a **+50dB fade margin** at 10km, this system will be virtually "un-glitchable" at any distance a human pilot can see a model aircraft. The primary limiting factor will be local interference from the airplane's own ESC and servos.

---
*Reference: Friis Transmission Equation & ITU-R P.525-4.*

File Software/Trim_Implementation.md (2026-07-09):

# Trim Implementation: Mechanical vs. Digital

In radio control, "Trim" is used to fine-tune the neutral position of your control surfaces (ailerons, elevator, rudder) so the airplane flies straight without stick input. For your Kraft 7 conversion, you have two choices.

## 1. Option A: Mechanical Trim (The "Vintage" Way)

The original Kraft 7 uses mechanical levers that physically rotate the body of the stick potentiometers.

- **How it works**: When you move the small slider next to the stick, it physically shifts the pot. The ESP32 simply sees a different analog value at "center."
- **Wiring**: No extra wiring is needed.
- **Code**: No extra code is needed.
- **Pros**: Maintains the 100% original look and feel of the Kraft radio.
- **Cons**: No Model Memory. If you fly two different planes, you have to manually move the physical sliders every time you swap.

---

## 2. Option B: Digital Trim (The "Modern" Way)

In this approach, you ignore or remove the mechanical sliders and add small buttons (or 5-way navigation switches) to the case.

- **How it works**: The ESP32 maintains a `trim_value` variable in its memory for each axis.
- **Math**: `Final_Output = Raw_Stick_Value + Trim_Value`.
- **Pros**: 
    - **Model Memory**: The ESP32 can save different trim settings for 10+ different airplanes.
    - **Precision**: You can adjust trim in very small, repeatable increments.
    - **Audible Feedback**: You can program the ESP32 to "beep" when you center the trim.

---

## 3. Implementing Digital Trim in Code

To use Digital Trim, you need to add four momentary buttons (Up/Down for Ele, Left/Right for Ail/Rud).

### Logic Snippet:
```cpp
int trim_ail = 0; // Ranges from -100 to +100

void handleTrims() {
  if (digitalRead(TRIM_AIL_LEFT) == LOW) {
    trim_ail--;
    playBeep(); // Audio feedback
    saveToMemory(); // Save to ESP32 Flash/NVS
  }
  if (digitalRead(TRIM_AIL_RIGHT) == LOW) {
    trim_ail++;
    playBeep();
    saveToMemory();
  }
}

// Applying the trim
int final_aileron = raw_aileron + trim_ail;
```

## 4. Recommendation for ne9n
Since you are building a modern 50MHz digital link, **Option B (Digital Trim)** is the better choice. It allows you to take full advantage of the ESP32's memory. You can hide the buttons inside the case or mount them subtly near the original trim slots.

---
*Created for the Kraft 7 Digital Conversion Project.*

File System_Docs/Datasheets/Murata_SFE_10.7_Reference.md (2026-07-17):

# Murata CERAFIL® SFE10.7 Series Reference

This document provides the technical specifications for the 10.7 MHz ceramic IF filter used in the RX design.

## 1. Primary Specifications (SFE10.7MS2)

| Parameter | Value |
| :--- | :--- |
| **Center Frequency (fc)** | 10.700 MHz ± 30 kHz |
| **3dB Bandwidth** | 230 kHz ± 50 kHz |
| **20dB Bandwidth** | 600 kHz (max) |
| **Insertion Loss** | 6.0 dB (max) |
| **Input/Output Impedance**| 330 $\Omega$ |
| **Spurious Response** | 40 dB (min) [9-12 MHz] |

## 2. Physical Dimensions & Pinout
**Package Type**: Through-Hole Ceramic (Standard 3-pin)
- **Lead Pitch**: **2.5 mm** (between Pin 1-2 and 2-3)
- **KiCad Footprint**: `Filter:Filter_Ceramic_Murata_SFE_7.0x7.0mm_P2.50mm`

```text
      _______
     |       |
     | 10.7S |  <-- Marking (Example)
     |_______|
       | | |
       1 2 3
```

| Pin | Function | Connection |
| :--- | :--- | :--- |
| **1** | **Input** | From Mixer OUT+ (LT5560 Pin 5) |
| **2** | **Ground** | System Ground Plane |
| **3** | **Output** | To ESP32 ADC Input |

## 3. Matching Requirements
To achieve the specified bandwidth and ripple, the filter must be terminated with **330 $\Omega$**. 
- In our design, the LT5560 output impedance should be checked. 
- If the MCU ADC input impedance is high, a parallel 330 $\Omega$ resistor to ground may be required at Pin 3 to ensure proper filter performance.

## 4. Official Documentation
Full catalog data can be found in **Murata Catalog No. P61E-6**.
- [Murata Ceramic Filters for FM Receivers](https://www.murata.com/en-global/products/filter/ceramicfilter/catalog)

---
*Reference for the Kraft-6M 50MHz Receiver Project.*

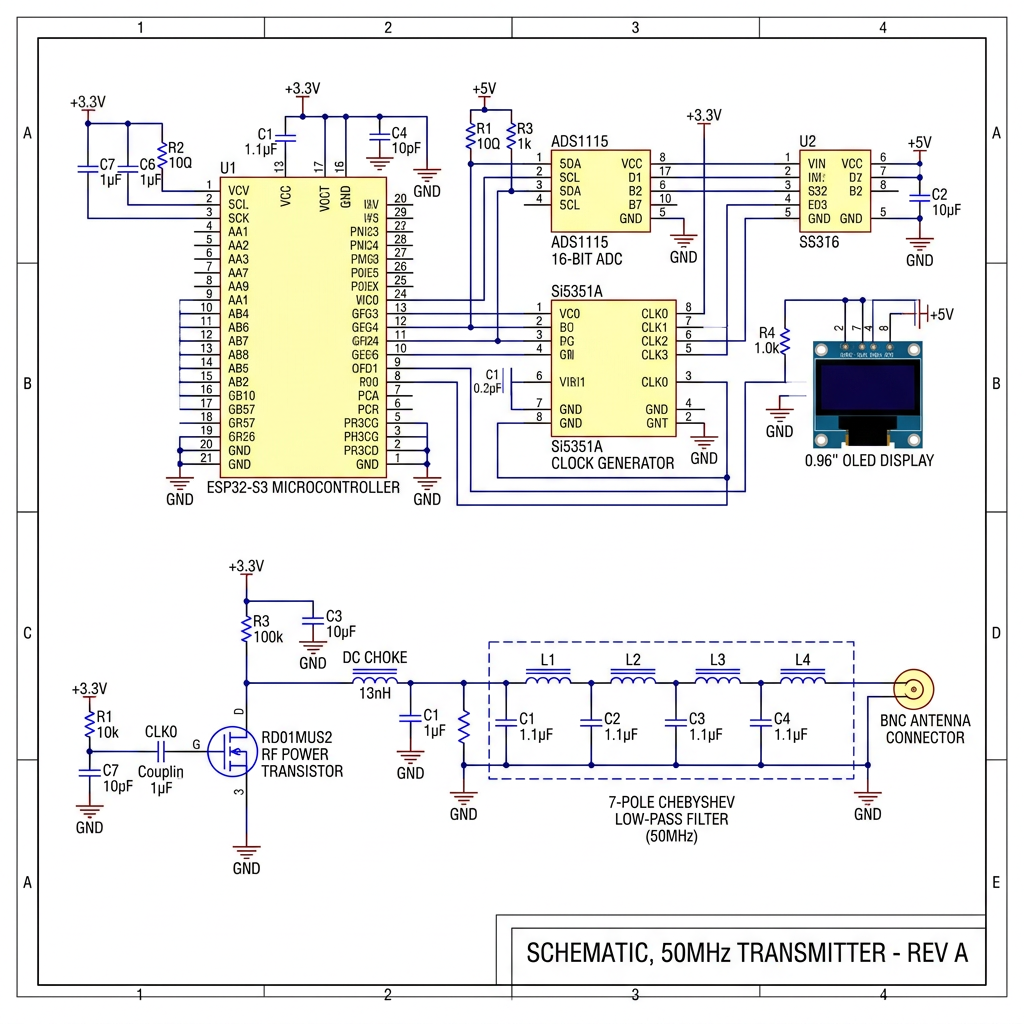
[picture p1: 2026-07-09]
TX_Hardware/TX_Schematic_Reference.png

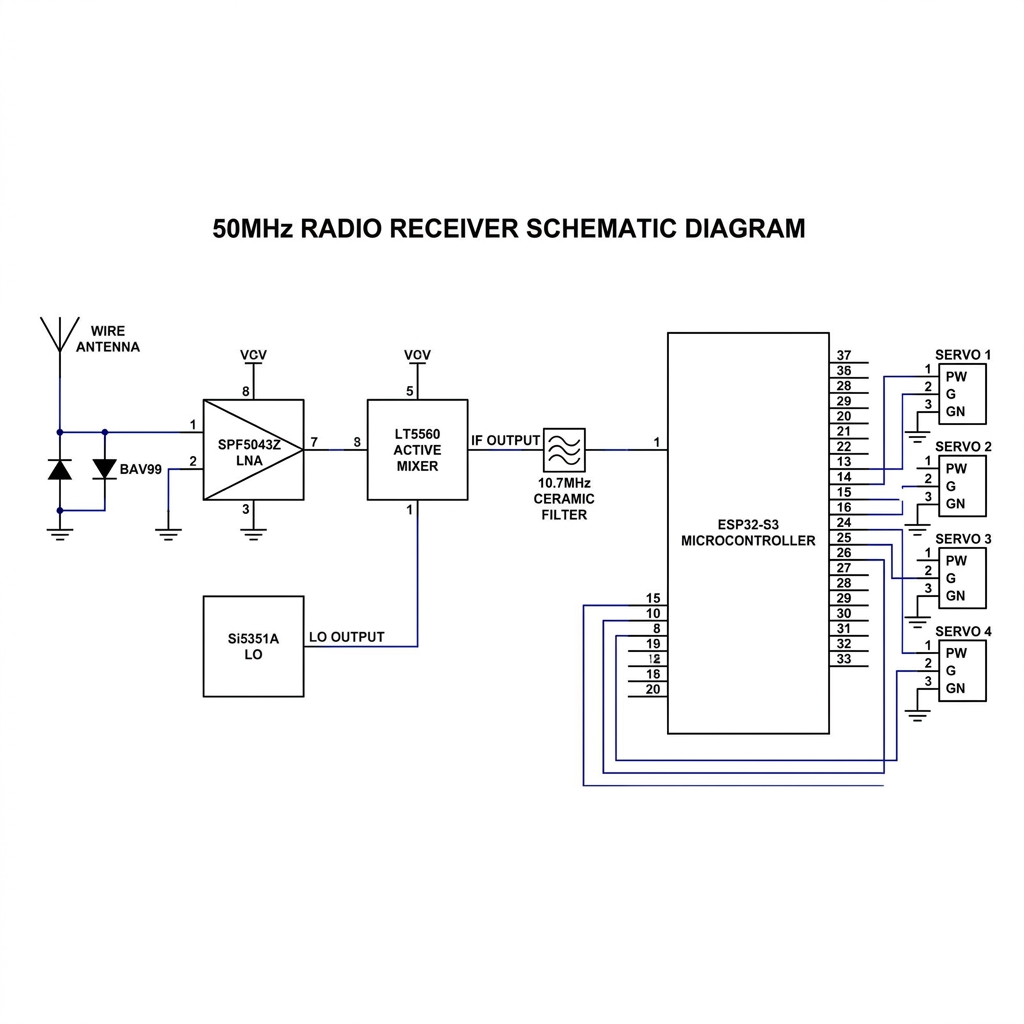
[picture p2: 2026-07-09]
RX_Hardware/RX_Schematic_Reference.png

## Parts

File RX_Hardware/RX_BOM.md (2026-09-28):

# 50MHz Receiver: Bill of Materials (BOM)

This list contains the core components required to build one 50MHz high-sensitivity receiver with integrated 2-way telemetry.

## 1. Core Integrated Circuits (Logic & Power)

| Component | Part Number | Description | Qty | Source |
| :--- | :--- | :--- | :--- | :--- |
| **MCU** | ESP32-S3-WROOM-1 | ESP32-S3 Module (Dual-core, 16MB Flash) | 1 | [DigiKey](https://www.digikey.com/en/products/detail/espressif-systems/ESP32-S3-WROOM-1-N16R8/15970929) |
| **Synthesizer** | Si5351A-B-GT | I2C Clock Generator (LO + Telemetry) | 1 | [DigiKey](https://www.digikey.com/en/products/detail/skyworks-solutions-inc/SI5351A-B-GT/3847847) |
| **Regulator** | AP2112K-3.3TRG1 | 3.3V 600mA LDO Regulator | 1 | [DigiKey](https://www.digikey.com/en/products/detail/diodes-incorporated/AP2112K-3-3TRG1/4470746) |
| **Current Sensor**| INA219AIDCNR | I2C Current/Power Monitor (Telemetry) | 1 | [DigiKey](https://www.digikey.com/en/products/detail/texas-instruments/INA219AIDCNR/2135017) |

## 2. RF Path Components

### 2.1 Receiver Stage
| Component | Part Number | Description | Qty | Note |
| :--- | :--- | :--- | :--- | :--- |
| **LNA** | SPF5043Z | Low Noise MMIC Amplifier (0.8dB NF) | 1 | Front-end |
| **Active Mixer** | LT5560EDD#PBF | Active Mixer (50MHz -> ~169MHz IF, LO 118.2MHz) | 1 | Up-converter |
| **IF Band-Pass** | ~168.75 MHz | 3-pole LC BPF, ~3-5MHz BW, 50 Ohm (values TBD) | 1 set | Rejects LO/RF feedthrough |
| **FSK Receiver** | Si4463-C2A-GM | EZRadioPRO sub-GHz transceiver, QFN-20 4x4mm, receive-only | 1 | Demod, AFC, sync, RSSI (SPI) |
| **Crystal (Si4463)** | 30.000 MHz | 3225, <=+-10 ppm preferred (internal load caps) | 1 | Si4463 reference |
| **Si4463 RX Match** | 169 MHz | Single-ended -> differential match per Silicon Labs AN643 (values TBD) | 1 set | |
| **Resistor** | 10 kOhm | 0603, Si4463 nIRQ pull-up | 1 | |

*Removed 2026-09-28:* 10.7MHz ceramic IF filter (Murata SFE) and the CD74HC4046A PLL
discriminator (+ its timing R/C, loop filter and demod RC LPF) -- replaced by the Si4463
upconversion receiver (see `RX_Design_Details.md`).

### 2.2 Telemetry Transmitter Stage
| Component | Part Number | Description | Qty | Note |
| :--- | :--- | :--- | :--- | :--- |
| **RF Switch** | BGS12PL6 | SPDT T/R Switch | 1 | Antenna Sharing |
| **Crystal** | 26.000 MHz | For Si5351A Reference | 1 | 8pF Load |

## 3. Passives & Connectors

| Component | Value | Description | Qty | Note |
| :--- | :--- | :--- | :--- | :--- |
| **Servo Headers** | 0.1" (2.54mm) | 3-pin Male Headers (Breakaway) | 8 | PWM Out |
| **Bulk Cap** | 470 uF | Electrolytic (Servo Rail Buffer) | 1 | |
| **LDO VCC** | 10 uF | 0805 X7R (LDO Input/Output) | 2 | |
| **RF Path Caps** | 100 pF | 0603 C0G/NP0 (RF Coupling) | 8 | Increased qty |
| **Inductor (Match)**| 220 nH | 0603 Wirewound (LNA Match) | 2 | 50MHz Tuned |
| **Inductor (RFC)** | 1.0 uH | 0805 Power Inductor (LNA Bias) | 1 | |
| **Protection** | SS14 | Schottky Diode (Reverse Polarity) | 1 | |
| **Power Filter** | 10 uH | 0805 Power Inductor (LC Filter) | 1 | |
| **Decoupling Caps**| 0.1 uF | 0603 X7R (Digital Bypassing) | 12 | +2 for Si4463 VDD |
| **Decoupling Caps**| 1 uF / 10 pF | 0402 X7R / C0G (Si4463 VDD pins 6, 8) | 2 / 1 | |

## 4. Total Cost Estimate
- **Core Silicon**: ~$22.00
- **Passives & Connectors**: ~$8.00
- **Total per RX**: **~$30.00 USD** (excluding PCB)

---
*Note: Prices are approximate and based on single-unit quantities as of 2024.*

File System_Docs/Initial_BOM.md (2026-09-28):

# Initial Bill of Materials (BOM) - 6m RC Transceiver

This is the initial parts list for the 50MHz digital RC link. It uses modern, active components available through major distributors (DigiKey, Mouser, etc.).

## 1. Primary Components (RF & Logic)

| RefDes | Part Number | Manufacturer | Description | Approx. Price |
| :--- | :--- | :--- | :--- | :--- |
| U1 | [Si5351A-B-GT](https://www.digikey.com/en/products/detail/skyworks-solutions-inc/SI5351A-B-GT/3679815) | Skyworks | I2C Programmable Clock Generator (Synthesizer) | $2.50 |
| U2 | [RD01MUS2-T113](https://www.rfparts.com/rd01mus2-t113.html) | Mitsubishi | 1W VHF/UHF RF MOSFET (PA) | $8.00 |
| U3 | [LT5560EDD#PBF](https://www.digikey.com/en/products/detail/analog-devices-inc/LT5560EDD-PBF/1590059) | Analog Devices | Low Power Active Mixer (40MHz - 4GHz) | $4.50 |
| U4 | [SPF5043Z](https://www.digikey.com/en/products/detail/qorvo/SPF5043Z/4836657) | Qorvo | Low Noise MMIC Amplifier (LNA) | $2.00 |
| U5 | [BGS12PL6E6327XTSA1](https://www.digikey.com/en/products/detail/infineon-technologies/BGS12PL6E6327XTSA1/2353386) | Infineon | SPDT RF Switch | $0.80 |
| U6 | [ESP32-S3-WROOM-1](https://www.digikey.com/en/products/detail/espressif-systems/ESP32-S3-WROOM-1-N8/15970878) | Espressif | Ground Station MCU (WiFi/BT) | $4.00 |
| U7 | [ESP32-S3-WROOM-1](https://www.digikey.com/en/products/detail/espressif-systems/ESP32-S3-WROOM-1-N8/15970878) | Espressif | Airplane RX MCU (Unified with TX) | $4.00 |
| U8 | [INA219AIDCNR](https://www.digikey.com/en/products/detail/texas-instruments/INA219AIDCNR/2135017) | TI | I2C Current/Power Monitor (Telemetry) | $2.50 |
| Y1 | [ECS-260-18-33-JGN-TR](https://www.digikey.com/en/products/detail/ecs-inc/ECS-260-18-33-JGN-TR/825413) | ECS Inc. | 26MHz TCXO / Crystal (Frequency Ref) | $1.00 |
| U9 | Si4463-C2A-GM | Silicon Labs | EZRadioPRO FSK receiver (142-1050MHz), receive-only, QFN-20 -- one per board (RX + TX telemetry) | TBD |
| Y2 | 30.000MHz crystal (3225, <=+-10ppm preferred) | TBD | Si4463 reference (own crystal, not shared with Si5351A) | TBD |

## 2. Filters & Passives

| Component | Value / Type | Note |
| :--- | :--- | :--- |
| **IF Filter** | ~169 MHz LC BPF | 3-pole LC band-pass, ~168.75MHz centre, 3-5MHz BW (values TBD). Replaces the 10.7MHz ceramic filter |
| **Si4463 RX Match** | per Silicon Labs AN643 | Single-ended to RXp/RXn differential match, 169MHz values |
| **LPF Inductors** | 120nH / 150nH | Wire-wound 0603 High-Q (Murata LQW series) |
| **PA RFC** | 1.0 uH | High-current inductor (400mA+) for DC feed |
| **Matching Caps** | C0G/NP0 | RF Grade capacitors (e.g., Murata GJM series) |

## 3. Connectors & Misc

| Component | Description |
| :--- | :--- |
| **Antenna (TX)** | 1.5m Telescoping Whip (BNC or SMA mount) |
| **Antenna (RX)** | 26AWG Silicone Wire (Trailing 1.5m) |
| **PCB (Air)** | 20x20mm 4-Layer (Recommended for RF performance) |
| **PCB (Ground)** | JR Module form factor (Standard RC expansion bay) |

---

### Total Estimated Prototype Cost (Silicon Only): ~$35.00 USD

> [!NOTE]
> The **LT5560** is used in this BOM as a modern, high-performance replacement for the obsolete SA612. It requires an external LO from the Si5351A but offers significantly better dynamic range and lower noise. It now **upconverts** 50MHz to a ~169MHz IF (118.2MHz LO) for the **Si4463** receiver, which does the FSK demodulation in hardware.

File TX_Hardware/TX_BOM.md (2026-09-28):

# 50MHz Transmitter: Bill of Materials (BOM)

This list contains the core components for the 1W Kraft 7 digital conversion.

## 1. Core Integrated Circuits

| Component | Part Number | Description | Qty | Source |
| :--- | :--- | :--- | :--- | :--- |
| **MCU** | ESP32-S3-WROOM-1 | ESP32-S3 Module (Dual-core, 16MB) | 1 | [DigiKey](https://www.digikey.com/en/products/detail/espressif-systems/ESP32-S3-WROOM-1-N16R8/15970929) |
| **RF Synthesizer** | Si5351A-B-GT | I2C Clock Generator | 1 | [DigiKey](https://www.digikey.com/en/products/detail/skyworks-solutions-inc/SI5351A-B-GT/3847847) |
| **Power MOSFET** | RD01MUS2-T113 | 1W RF Power Transistor (SOT-89) | 1 | [RF Parts](https://www.rfparts.com/rd01mus2-t113.html) |
| **Precision ADC** | ADS1115IDGSR | 16-bit 4-Ch I2C ADC | 2 | [DigiKey](https://www.digikey.com/en/products/detail/texas-instruments/ADS1115IDGSR/2060195) |
| **Display** | 1.3" OLED (SH1106) | I2C 128x64 Monochrome Display | 1 | [Amazon/eBay](https://www.amazon.com/s?k=1.3+inch+OLED+SH1106) |
| **RF Switch** | BGS12PL6 | SPDT T/R Switch (Telemetry) | 1 | [DigiKey](https://www.digikey.com/en/products/detail/infineon-technologies/BGS12PL6E6327XTSA1/2056263) |
| **LNA** | SPF5043Z | Low Noise MMIC Amplifier (RX Path) | 1 | [DigiKey](https://www.digikey.com/en/products/detail/qorvo/SPF5043Z/4694406) |
| **Active Mixer** | LT5560EDD#PBF | Active Mixer (RX Path, upconverts 50MHz -> ~169MHz IF) | 1 | [DigiKey](https://www.digikey.com/en/products/detail/analog-devices-inc/LT5560EDD-PBF/1590059) |
| **FSK Receiver** | Si4463-C2A-GM | EZRadioPRO sub-GHz transceiver, QFN-20 4x4mm, used receive-only (telemetry) | 1 | Silicon Labs / DigiKey |

## 2. RF & Passive Components

| Component | Value | Description | Qty |
| :--- | :--- | :--- | :--- |
| **Crystal** | 26.000 MHz | For Si5351A (8pF Load) | 1 |
| **Inductor (LPF)** | 180 nH | 0805 Wirewound (7-pole filter) | 3 |
| **Capacitor (LPF)** | 220 pF | 0805 C0G/NP0 (7-pole filter) | 2 |
| **Capacitor (LPF)** | 120 pF | 0805 C0G/NP0 (7-pole filter) | 2 |
| **RF Choke** | 1.0 uH | 1206 High-Current Inductor (PA Feed) | 1 |
| **Crystal (Si4463)** | 30.000 MHz | 3225 package, <=+-10 ppm preferred; Si4463 internal load caps | 1 |
| **IF Band-Pass** | ~168.75 MHz | 3-pole LC BPF, ~3-5MHz BW, 50 Ohm (0402/0603 C0G + wirewound L; values TBD) | 1 set |
| **Si4463 RX Match** | 169 MHz | Single-ended -> differential LNA match per Silicon Labs AN643 (values TBD) | 1 set |
| **Resistor (nIRQ pull-up)** | 10 kOhm | 0402/0603, Si4463 nIRQ to 3.3V | 1 |
| **Decoupling (Si4463)** | 100 nF, 1 uF, 10 pF | 0402 X7R/C0G at VDD pins 6/8 | 2/2/1 |

*Removed 2026-09-28:* 10.7MHz ceramic IF filter (FL1, Murata SFE) -- the telemetry receiver now
upconverts to ~169MHz and demodulates in an Si4463 (see `TX_Hardware/TX_Schematic_Blueprint.md`).

## 3. Power & Mechanical

| Component | Part Number | Description | Qty |
| :--- | :--- | :--- | :--- |
| **Buck Converter** | MP1584EN | 7-12V to 5V Step Down Module | 1 |
| **SMA Connector** | SMA-KWE | Right Angle PCB Mount SMA | 1 |
| **Stick Connectors**| JST-XH 3-Pin | 2.54mm Header & Socket (J1-J7) | 7 |
| **Power Connector** | JST-VH or XT30| High-current Battery Input (J8) | 1 |
| **Logic Connectors**| JST-XH 2/4-Pin | 2.54mm (J9 for Power, J10 for OLED) | 2 |
| **Antenna** | 50MHz Whip | Base-loaded or telescopic whip | 1 |

## 4. Total Cost Estimate
- **Core Silicon**: ~$32.00
- **Passives & Display**: ~$18.00
- **Total per TX**: **~$50.00 USD**

---
*Note: The RD01MUS2 is a specialized RF part and may require ordering from specialized vendors like RF Parts or Mouser.*

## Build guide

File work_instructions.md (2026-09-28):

# KiCad Schematic Wiring Instructions

## Status (2026-09-28): receive chain moved to Si4463 -- schematics updated, PCBs not yet

The receive chain on **both boards** (RX receiver and the TX's telemetry receiver) is now:
SPF5043Z LNA -> LT5560 **upconverter** (Si5351A LO fixed at 118.2MHz) -> ~169MHz LC
band-pass -> AN643 match -> **Si4463-C2A-GM** -> SPI -> ESP32-S3. This replaces the 10.7MHz
ceramic filter and the CD74HC4046A PLL discriminator / ADC path. See
`RX_Hardware/RX_Design_Details.md` and `RX_Hardware/RX_Schematic_Blueprint.md`.

**Both schematics now carry the new chain** (edited 2026-09-28, verified with `kicad-cli`
netlist export + ERC; no new ERC errors). The TX steps 8-9 below (10.7MHz filter -> ESP32 ADC)
are superseded. **Still to do:**
1. **PCBs**: open each project and run *Tools -> Update PCB from Schematic* -- the new parts
   (Si4463, crystal, IF filter, match, decoupling) aren't on either board yet, and pad
   assignments changed (see below).
2. **Component values**: IF band-pass (L/C "TBD"), LT5560 169MHz output feeds, and the Si4463
   RX match are placeholders. Design the band-pass with SPICE; take the match topology and
   values from Silicon Labs AN643 (169MHz) -- the schematic's 3-part match is a placeholder.
3. If KiCad had either project open during the edit, close it **without saving** before reopening.

`RX_50MHz_SDR.kicad_sch` -- fixed while adding the Si4463 (all were real netlist errors):
- Servo pins: the five ESP32 servo pins were shorted onto one net. Now CH1-8 = IO4, IO5,
  IO6, IO7, IO15, IO16, IO1, IO2 -> J5-J12, one net each.
- Si5351A/INA219 I2C now reaches the ESP32 (SDA = IO8, SCL = IO9).
- RF chain: J1 went straight to the LNA past the T/R switch, the LNA never reached the mixer
  (C3 open, mixer IN+ was on the T/R control line), and Si5351 CLK0 drove the mixer's OUT-
  pin. Now J1 -> U6 ANT, U6 RF1 -> C2 -> LNA, C3 -> LT5560 IN+, CLK0 -> LO+, CLK1 -> C1 -> U6
  RF2, C5 -> IN-, C7 -> OUT-.
- T/R switch CTRL = IO10, LT5560 EN (`RX_EN`) = IO21. The custom ESP32 symbol gained IO1,
  IO2, IO13, IO14, IO21.
- Si4463 on SPI: SCLK IO12, MOSI IO11, MISO IO13, nSEL IO14, nIRQ IO17, SDN IO18.

Still wrong in the RX schematic (not touched -- outside this change):
- ESP32 auto-reset: `EN`/`BOOT_IO0` labels dangle; Q1/Q2 aren't connected to anything.
- The CP2102N is on a separate `+3V3` net from the main `3V3` rail (it has no supply).
- Y1 (26MHz) is a 2-pin symbol on the 4-pad 3225 footprint, so Si5351 XB lands on a GND pad.
- C4 (10nF) shunts the LNA output node to GND; it belongs on the 3V3 side of RFC L3.
- No 50MHz band-pass between LNA and mixer, although the block diagram shows one.
- `XTAL_B`/`VIN_LDO` labels dangle; AP2112K VIN has no power flag.

`TX_50MHz_1W.kicad_sch` -- fixed while adding the Si4463:
- **ESP32 pad numbers**: the `Kraft6M:ESP32-S3-WROOM-1` symbol had IO8/IO9/IO10/IO11 on pads
  11/12/13/14 (really IO18, IO8, USB D-, USB D+). Now 12/17/18/19, in both the schematic and
  `KiCad_Libraries/Kraft6M.kicad_sym`. IO12-IO17 added.
- LT5560 IN-/LO-/OUT- were tied straight to GND -- now AC-grounded (C27/C28/C29, as on the RX).
- SPF5043Z LNA had no bias feed and was DC-coupled into the mixer -- added L7 (1uH RFC), C25,
  C26 (DC block).
- FL1 and `ADC_IN` removed; IO10 is now free (no-connect flag).

Still wrong in the TX schematic (not touched): ADS1115 U7 has SDA/SCL swapped relative to the
bus; Q3 base and R9 are unconnected (auto-reset); AP2112K EN unconnected.

## Why Manual Wiring is Required

KiCad schematics (`.kicad_sch`) are 2D geometric drawings. While Antigravity can generate netlists and inject component symbols into the schematic files, it cannot safely draw the physical wires between them. 

Automated wire routing without spatial awareness of the canvas would result in wires crossing over components, obscuring text, and creating unintended short circuits. Therefore, placing the injected components and drawing the connecting lines is a step that requires a human in the KiCad GUI.

---

## Wiring Checklist

The telemetry components have been injected into your schematic sheets. Open KiCad, locate the un-wired components near the top of the sheets, and use the **Wire Tool (`W`)** and the **Move Tool (`G` to drag with wires, `M` to move freely)** to make the following connections.

### 📡 Transmitter (Ground Station) - `TX_50MHz_1W.kicad_sch`

1. **Move (`G`)** the new `BGS12PL6` Switch between the `RD01MUS2` PA output and the Antenna.
2. Wire **PA Drain** → **Switch RF1 (Pin 3)**.
3. Wire **Switch ANT (Pin 5)** → **Low Pass Filter**.
4. Wire **Switch CTRL (Pin 4)** → **ESP32 GPIO 10**.
5. Wire **Switch RF2 (Pin 1)** → **SPF5043Z LNA Input (Pin 1)**.
6. Wire **LNA Output (Pin 3)** → **LT5560 Mixer IN+ (Pin 1)**.
7. Wire **Si5351A CLK1 (Pin 7)** → **LT5560 Mixer LO+ (Pin 7)**.
8. ~~Wire **LT5560 IF Output (Pin 5)** → **10.7MHz Filter Input**.~~ Superseded: → **~169MHz LC BPF** → **Si4463** (see status above).
9. ~~Wire **10.7MHz Filter Output** → **ESP32 ADC Pin**.~~ Superseded: Si4463 connects to the ESP32 over SPI + nIRQ + SDN.

### 🛩️ Receiver (Airborne) - `rx_n.kicad_sch`

1. **Move (`G`)** the `BGS12PL6` Switch to the Antenna input.
2. Wire **Antenna** → **Switch ANT (Pin 5)**.
3. Wire **Switch RF2 (Pin 1)** → **LNA Input (SPF5043Z Pin 1)**.
4. Wire **Si5351A CLK1 (Pin 7)** → **Switch RF1 (Pin 3)**.
5. Wire **ESP32 GPIO 10** → **Switch CTRL (Pin 4)**.
6. **Move (`G`)** the `INA219` sensor near the Power input block.
7. Wire **INA219 IN+ (Pin 1)** → **BATT+**.
8. Wire **INA219 IN- (Pin 2)** → **ESC / Main Power Rail**.
9. Wire **INA219 SDA / SCL** to the **ESP32 I2C pins**.

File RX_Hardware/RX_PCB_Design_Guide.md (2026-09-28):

# 50MHz Receiver PCB Design Guide

This document provides technical guidance for laying out the custom 50MHz receiver PCB for aircraft installation.

## 1. Physical Specifications
- **Form Factor**: Target size of **30mm x 50mm**.
- **Mounting**: 4x M2 mounting holes at the corners.
- **Connectors**:
    - **RF In**: Single pin/solder pad for 1.5m wire antenna (or U.FL connector).
    - **Servo Out**: 4 to 8 standard 3-pin 0.1" male headers.
    - **Power In**: 5V from ESC (via servo rail).

---

## 2. PCB Stackup (4-Layer Recommended)
RF sensitivity at 50MHz requires a stable ground reference.
- **Layer 1 (Top)**: RF signal traces, LNA, Mixer, 169MHz IF band-pass and Si4463.
- **Layer 2 (Internal)**: **Solid Ground Plane** (No signal traces).
- **Layer 3 (Internal)**: Power Planes (3.3V for ESP32, 5V for Servos).
- **Layer 4 (Bottom)**: Ground Plane and low-speed digital signals (PWM).

---

## 3. Component Placement & Partitioning

To maximize sensitivity, the board must be split into three distinct zones:

### 3.1 Zone A: RF Front-End (High Sensitivity)
- Place the **SPF5043Z LNA** as close to the antenna input as possible.
- Keep the path to the **LT5560 Mixer** short and direct.
- **Isolation**: Use a ground pour "moat" around the LNA section to keep digital noise out.

### 3.2 Zone B: IF & LO (Frequency Synthesis)
- Place the **Si5351A** and its 26MHz crystal in the center.
- Route the LO signal to the Mixer using a short, impedance-controlled trace.
- The **169MHz LC IF band-pass** goes immediately after the Mixer output, then the AN643 match
  straight into the **Si4463** RXp/RXn pins. Keep this whole IF section **compact and shielded**
  (can footprint or via-fenced pour): 169MHz is not a clear band, so direct IF pickup is a layout
  problem, not a frequency-plan one.
- Place the Si4463's **30MHz crystal** right against XIN/XOUT (pins 17/16), with no traces routed
  under it, and keep it away from the Si5351A crystal and LO trace.
- The Si4463 **exposed pad is its main ground**: via-stitch it (thermal-via footprint) directly to
  the Layer 2 plane.

### 3.3 Zone C: Digital & Servos (High Current)
- Place the **ESP32-S3** at the far end of the board, away from the LNA.
- The **Servo Headers** should be at the edge of the board.
- **Bulk Capacitance**: Place a large (470uF) electrolytic capacitor near the servo power input to buffer current spikes.

---

## 4. RF Layout Principles

### 4.1 Trace Impedance
- All RF traces (Antenna to LNA, LNA to Mixer) should be calculated for **50 Ohm Impedance**.
- For a standard 1.6mm 4-layer board (Top to L2 ground), this is typically a **0.35mm** wide trace.

### 4.2 Ground Stitching
- Use a "Via Wall" (vias spaced 2-3mm apart) along the edges of the RF traces and around the LNA section to prevent EMI leakage.
- Ensure every ground pad on the LT5560 and SPF5043Z has at least 2 vias directly to the Layer 2 ground plane.

---

## 5. Physical Layout Concept (Floorplan)

```mermaid
graph TD
    subgraph "RX PCB (30x50mm)"
        ANT["ANT PAD"] --- LNA["SPF5043Z"]
        LNA --- MIX["LT5560"]
        SI["Si5351A"] --- MIX
        MIX --- FILT["169MHz IF BPF"]
        FILT --- SI44["Si4463 (shielded IF)"]
        SI44 -- "SPI" --- MCU["ESP32-S3"]
        MCU --- SERVO["Servo Header Row"]
    end
```

---

## 6. Power Supply
- Use a high-quality **3.3V LDO** (e.g., AP2112) to power the ESP32 and RF chips from the 5V servo rail.
- Add an **LC Filter** (inductor + capacitor) on the 3.3V line feeding the LNA to block digital switching noise from the ESP32.

---
*Reference: Analog Devices RF Layout Best Practices & ESP32-S3 Hardware Design Guidelines.*

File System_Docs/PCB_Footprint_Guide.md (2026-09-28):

# PCB Footprint & Assembly Guide

This guide provides the specific SMT footprint requirements and soldering advice for the 50MHz RC project.

## 1. Core Component Footprints

| Component | Function | Footprint Name | Dimensions / Pitch | Note |
| :--- | :--- | :--- | :--- | :--- |
| **ESP32-S3-WROOM-1** | MCU | `RF_Module:ESP32-S3-WROOM-1` | 1.27mm Pitch | Standard Espressif Footprint |
| **Si5351A-B-GT** | Synth | `Package_SO:MSOP-10_3x3mm_P0.5mm` | 0.5mm Pitch | Small, requires fine soldering |
| **ADS1115IDGS** | ADC | `Package_SO:VSSOP-10_3x3mm_P0.5mm` | 0.5mm Pitch | Same footprint as Si5351A |
| **RD01MUS2** | 1W PA | `Package_TO_SOT_SMD:SOT-89-3` | Thermal Tab | Solder center pad to GND plane |
| **LT5560EDD** | Mixer | `Package_DFN_QFN:DFN-8-1EP_3x3mm_P0.5mm`| 0.5mm Pitch | Exposed Pad (EP) is critical |
| **Si4463-C2A-GM** | FSK Receiver | `Package_DFN_QFN:QFN-20-1EP_4x4mm_P0.5mm_EP2.6x2.6mm_ThermalVias` | 0.5mm Pitch | EP to GND with vias; 30MHz crystal right next to XIN/XOUT |
| **SPF5043Z** | LNA | `Package_TO_SOT_SMD:SOT-343` | 1.3mm / 0.65mm | RF Optimized pinout |
| **AP2112K** | LDO | `Package_TO_SOT_SMD:SOT-23-5` | 0.95mm Pitch | Standard regulator |

---

## 2. Passive Component Sizes
To balance ease of hand-soldering with RF performance:
- **0805 (2012 Metric)**: Recommended for Power Amplifiers (TX) and high-current paths.
- **0603 (1608 Metric)**: Recommended for all RF signals and general decoupling.
- **0402 (1005 Metric)**: Avoid unless you have a microscope; not needed for 50MHz.

---

## 3. Critical Solder Mask & Stencil Advice
- **Thermal Pads**: For the **RD01MUS2**, **LT5560** and **Si4463**, the center thermal pad MUST be connected to the bottom ground plane using a cluster of 4-9 "Thermal Vias" (0.2mm - 0.3mm diameter).
- **RF Traces**: Do not allow solder mask to cover 50-ohm RF traces if you are doing professional impedance control; however, for 50MHz, standard mask is acceptable.
- **Solder Paste**: Use **Lead-Free SAC305** or **Leaded Sn63/Pb37** for easiest hand assembly.

---

## 4. Connector Footprints
- **Servo Headers**: `Connector_PinHeader_2.54mm:PinHeader_1x03_P2.54mm_Vertical`
- **SMA Connector**: `Connector_Coaxial:SMA_Amphenol_132203_Vertical`
- **I2C / OLED**: `Connector_PinHeader_2.54mm:PinHeader_1x04_P2.54mm_Vertical`

---
*Reference: IPC-7351B Standard for Surface Mount Design.*

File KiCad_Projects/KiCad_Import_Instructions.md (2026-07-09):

# How to Import this Project into KiCad

I have generated the core **Netlist (.net)** files for both the Transmitter and Receiver. These files contain all the electrical connections (nets) and footprint assignments.

## 🛠️ Step 1: Create a New Project in KiCad
1.  Open KiCad and create a new project named `RX_50MHz_SDR` or `TX_50MHz_1W`.
2.  Place the `.net` file I generated into that project folder.

## ⚡ Step 2: Import the Schematic
1.  Open the **Schematic Editor** (`.kicad_sch`).
2.  Go to **File > Import > Netlist...**
3.  Select the corresponding `.net` file.
4.  KiCad will automatically populate the schematic with all the components and their connections.

## 📏 Step 3: Start the PCB Layout
1.  Open the **PCB Editor** (`.kicad_pcb`).
2.  Go to **Tools > Update PCB from Schematic...**
3.  All footprints will appear, pre-wired with "ratsnest" lines showing the connections defined in the Netlist.

---

## 🏗️ RX Board Layout Concept (Copy into KiCad PCB Editor)
To help you start the layout, I have calculated the **Board Outline (30x50mm)**. You can draw this on the `Edge.Cuts` layer:

- **Top Left**: (0, 0)
- **Top Right**: (50, 0)
- **Bottom Right**: (50, 30)
- **Bottom Left**: (0, 30)

### Placement Zones:
1.  **RF Front End**: Keep U3 (LNA) and U2 (Mixer) in the top-left corner.
2.  **MCU**: Place U1 (ESP32) in the center-right.
3.  **IO**: Place J1-J8 (Servo Headers) along the bottom edge for easy wiring.

---

## 🏗️ TX Board Layout Concept
- **Board Outline**: **60x80mm** (To fit the Kraft battery bay or internal deck).
- **PA Section**: Place Q1 (RD01MUS2) near the top SMA connector with a large ground pour for cooling.
- **Sticks**: Place U3/U4 (ADCs) near the joystick assembly for short analog wires.

---
*Files generated at: \KiCad_Projects\*

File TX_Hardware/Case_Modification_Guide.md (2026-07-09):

# Kraft 7: Case Modification & Mechanical Integration

This guide details how to modify the vintage Kraft 7 gold-anodized aluminum case to accommodate modern digital components while preserving its classic aesthetic.

## 1. Component Placement Strategy

| Component | Recommended Location | Installation Method |
| :--- | :--- | :--- |
| **1.3" OLED** | Top Center (above the Kraft Logo) | Rectangular cutout; flush mount with 3D printed bezel. |
| **USB-C Port** | Bottom Plate (original charge jack location) | Step-drill to 10mm; mount panel-mount USB-C extension. |
| **ESP32-S3 Deck** | Internal Center | Mount on 3mm standoff plate attached to rear case half. |
| **50MHz Antenna** | Top Right (original location) | Standard SMA-to-stud bulkhead adapter. |
| **LiPo Battery** | Original Battery Bay | Secure with high-density foam and velcro strap. |

---

## 2. The "Digital Deck" (Internal Sub-Chassis)
To avoid drilling excessive holes in the original case, create a **3D printed or FR4 "Digital Deck"** that mounts to the existing joystick assembly screws.

- **Stackup**:
    1. Bottom: 2S LiPo.
    2. Middle: ADS1115 and Power Distribution Board.
    3. Top: ESP32-S3 and 1W Power Amplifier (needs clear airflow).

---

## 3. Cutting the Aluminum Case

### 3.1 OLED Cutout
- **Tools**: Dremel with reinforced cutoff wheel, small needle files.
- **Dimensions**: 35mm x 18mm for a 1.3" SH1106 display.
- **Tip**: Apply blue painter's tape to the face of the radio before cutting to prevent scratches to the gold anodizing.

### 3.2 USB-C Integration
- Remove the old round DIN charge jack.
- Use a **USB-C Panel Mount Cable** (short 10cm version) to bridge from the internal charger to the exterior. This allows you to charge without opening the case.

---

## 4. Mechanical Preservation Rules
- **DO NOT** remove the original mechanical trim levers. We will disconnect their internal linkage but keep the external levers for "fidget" and aesthetic value.
- **DO NOT** paint the case. The original Kraft Gold is iconic.
- **WIRING**: Use braided cable sleeves for a "period-correct" look for any wires visible through the back or battery door.

---

## 5. Heat Management (1W PA)
The **RD01MUS2** transistor will generate heat during long flights.
- Ensure the PA is mounted on a small copper heat spreader.
- Solder the thermal tab of the SOT-89 package to a large ground plane area on your PCB.

---
*Created for the Kraft 7 "Restomod" Project.*

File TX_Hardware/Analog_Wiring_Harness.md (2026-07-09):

# Kraft 7: Analog Stick & Switch Wiring Harness

This document details the physical connection between the original Kraft joystick potentiometers, auxiliary knobs, and the new ADS1115 ADC.

## 1. Potentiometer Wiring (Standard Kraft)
Most vintage Kraft radios use **5k Ohm** or **10k Ohm** potentiometers. To interface with the 3.3V digital system, we must provide a stable reference voltage.

### 1.1 The Common Analog Bus
To minimize wiring clutter, use a common bus for Power and Ground that daisy-chains between all pots.

| Wire Color (Suggested) | Function | Connection |
| :--- | :--- | :--- |
| **Red** | **VCC (3.3V)** | Pin 1 of ALL Potentiometers |
| **Black** | **GND** | Pin 3 of ALL Potentiometers |
| **White/Yellow** | **Signal (Wiper)**| Pin 2 (Center) to ADC Inputs |

---

## 2. ADC Input Mapping (7 Channels)

To achieve high-resolution across all 7 channels, we use **two ADS1115 modules** on the same I2C bus.

### 2.1 Primary ADC (Address: 0x48) - Main Sticks
| ADC Input | Channel | Function | Kraft Stick Location |
| :--- | :--- | :--- | :--- |
| **AIN0** | 1 | **Aileron** | Right Stick (Horizontal) |
| **AIN1** | 2 | **Elevator** | Right Stick (Vertical) |
| **AIN2** | 3 | **Throttle** | Left Stick (Vertical) |
| **AIN3** | 4 | **Rudder** | Left Stick (Horizontal) |

### 2.2 Secondary ADC (Address: 0x49) - Aux & Trims
*Connect the **ADDR** pin of the second ADS1115 to **VDD** to change its address.*

| ADC Input | Channel | Function | Kraft Location |
| :--- | :--- | :--- | :--- |
| **AIN0** | 5 | **Aux 1** | Top Left Knob/Lever |
| **AIN1** | 6 | **Aux 2** | Top Right Knob/Lever |
| **AIN2** | 7 | **Aux 3** | Side Switch/Slider |
| **AIN3** | 8 | **Battery Sense**| LiPo Voltage Divider |

---

## 3. Physical Connector Suggestion
Since you are rebuilding the "deck," I recommend using **JST-XH (2.54mm)** connectors for the stick assemblies. This allows you to easily remove the sticks for maintenance.

- **4x 3-Pin JST-XH**: One for each main stick axis (VCC, GND, Wiper).
- **3x 3-Pin JST-XH**: For the auxiliary controls.

---

## 4. Wiring Diagram (Schematic View)

```mermaid
graph TD
    subgraph "Analog Bus"
        VREF[3.3V LDO Output] --- P1V[Pot 1 VCC]
        VREF --- P2V[Pot 2 VCC]
        VREF --- P3V[Pot 3 VCC]
        GND[System GND] --- P1G[Pot 1 GND]
        GND --- P2G[Pot 2 GND]
        GND --- P3G[Pot 3 GND]
    end
    
    P1W[Pot 1 Wiper] --> AIN0[ADS1115 AIN0]
    P2W[Pot 2 Wiper] --> AIN1[ADS1115 AIN1]
    P3W[Pot 3 Wiper] --> AIN2[ADS1115 AIN2]
```

---
*Note: If your original Kraft pots are scratchy or have large dead-zones, consider replacing them with modern Hall Effect sensors (e.g., Honeywell SS49E) which connect exactly the same way (VCC, GND, Out).*

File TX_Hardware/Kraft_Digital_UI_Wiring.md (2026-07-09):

# Kraft Digital: Wiring Schematic & OLED UI Design

This document details the hardware interconnections and the user interface design for the Kraft 7 Digital Conversion.

## 1. Wiring Schematic

The system uses a shared **I2C Bus** (SDA/SCL) to communicate between the ESP32, the high-precision ADC, the OLED display, and the RF Synthesizer.

### 1.1 Pin Mapping (ESP32-S3)

| Peripheral | Pin | Connection | Note |
| :--- | :--- | :--- | :--- |
| **I2C SDA** | GPIO 8 | ADS1115, OLED, Si5351 | Shared Data Bus |
| **I2C SCL** | GPIO 9 | ADS1115, OLED, Si5351 | Shared Clock Bus |
| **Aux SW 1** | GPIO 1 | Toggle Switch | Dual Rates / Mode |
| **Aux SW 2** | GPIO 2 | Toggle Switch | Gear / Aux |
| **Aux Pot 1** | GPIO 3 | Center Wiper | Analog Aux Channel (Internal ADC) |
| **RF EN** | GPIO 10 | PA Bias Enable | Enables the 1W Transmitter |
| **Status LED** | GPIO 21 | WS2812B (Built-in) | System Health / Link Status |

### 1.2 ADC Wiring (ADS1115 - High Precision)

To ensure smooth, "jitter-free" control, the four primary flight axes are connected to the 16-bit ADS1115.

| Stick Axis | Kraft Pot terminal | ADS1115 Pin |
| :--- | :--- | :--- |
| **Aileron** | Center Wiper | A0 |
| **Elevator** | Center Wiper | A1 |
| **Throttle** | Center Wiper | A2 |
| **Rudder** | Center Wiper | A3 |

> [!IMPORTANT]
> **Voltage Reference**: Connect the top terminal of all Kraft potentiometers to the ESP32 **3.3V** rail and the bottom terminal to **GND**. This ensures the stick range is within the ADC's safe operating window.

---

## 2. OLED UI Design (1.3" SH1106)

The display is divided into three logical zones: Status, Flight Data, and Telemetry.

### 2.1 Screen Layout Mockup

```text
+------------------------------------------+
| NE9N-TX      [8.4V]      LQ: 100% (RSSI) | <--- Status Bar
+------------------------------------------+
|                                          |
|    THR: [|||||     ]    AIL: ---|---     |
|    RUD: [|||||||   ]    ELE: ---|---     | <--- Stick Monitor
|                                          |
+------------------------------------------+
| PLANE: 12.6V | TIMER: 05:42 | RATE: HIGH | <--- Telemetry Bar
+------------------------------------------+
```

### 2.2 Visual Elements
- **Callsign (Top Left)**: Required for Amateur Radio digital identification.
- **LQ (Link Quality)**: Percentage of successful telemetry packets received back from the plane.
- **Stick Monitor**:
  - **Throttle/Rudder**: Horizontal progress bars.
  - **Ail/Ele**: Small "Crosshair" displays representing the gimbal position.
- **PLANE (Bottom Left)**: Real-time battery voltage of the airplane (via 50MHz telemetry).
- **RATE (Bottom Right)**: Indicates if the transmitter is in High or Low rates (Dual Rates).

---

## 3. Hardware Assembly Tips

1. **Shielded Cables**: Use shielded "servo wire" for the connections between the Kraft stick pots and the ADS1115. At 1W transmit power, RF interference can easily leak into the analog stick signals.
2. **I2C Pull-ups**: Ensure you have 2.2k or 4.7k pull-up resistors on the SDA/SCL lines. With three devices on the bus, the internal ESP32 pull-ups are usually insufficient.
3. **Mechanical Mounting**: Use the original Kraft RF deck mounting holes to secure a 3D-printed bracket for the ESP32 and RF modules.

---
*Created for the Kraft 7 "Restomod" Project.*

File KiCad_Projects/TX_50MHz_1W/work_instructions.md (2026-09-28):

# KiCad Schematic Wiring Instructions

## Status

### 📻 Telemetry Receiver — `TX_50MHz_1W.kicad_sch` — ✅ Si4463 chain in schematic, PCB not yet updated (2026-09-28)

The telemetry receive path is now *LT5560 upconverter → ~169MHz LC IF band-pass → Si4463 FSK
receiver → SPI* (was *LT5560 → 10.7MHz FL1 → ESP32 ADC*). Si5351A CLK1 is a fixed
**118.2MHz LO on PLLB**; CLK0 stays the FSK carrier on PLLA. Rationale, frequency plan and pin
tables: `TX_Hardware/TX_Schematic_Blueprint.md` and `RX_Hardware/RX_Design_Details.md`.

Done in the schematic (direct file edit, verified with `kicad-cli` netlist + ERC, no new errors):
1. FL1 and the `ADC_IN` net deleted; ESP32 **IO10** now has a no-connect flag.
2. LT5560 (U5): IN-/LO-/OUT- were tied straight to GND → now C27/C28 (100pF) and C29
   (10nF) AC grounds. OUT+/OUT- get DC feeds L8/L9 (value TBD), OUT+ → C30 → IF band-pass.
3. SPF5043Z (U4) had no bias feed → L7 1µH RFC from +3V3 (C25 10nF decoupling), and C26
   100pF DC block into the mixer.
4. 3-pole LC IF band-pass L10–L12 / C31–C35 (values TBD), placeholder AN643 match C36/L13/C37.
5. **U13 Si4463-C2A-GM** with Y2 30MHz (3225, 4-pad), C38–C42 decoupling, R13 10k nIRQ pull-up.
6. SPI + control: **SCLK = IO12, MOSI = IO13, MISO = IO14, nSEL = IO15, nIRQ = IO16, SDN = IO17**.
7. **ESP32 symbol pad numbers corrected**: IO8/IO9/IO10/IO11 were on pads 11/12/13/14 (really
   IO18, IO8, USB D-, USB D+) → now 12/17/18/19, in the schematic and in `Kraft6M.kicad_sym`.

**Still to do:**
- *Update PCB from Schematic* (new parts + changed ESP32 pad nets), then place/route them.
- Pick values: IF band-pass (SPICE), LT5560 169MHz output feeds, AN643 match topology/values.
- Unrelated issues seen in the netlist: ADS1115 U7 has SDA/SCL swapped; Q3 base and R9 are
  unconnected; AP2112K (U10) EN is unconnected.
- **If KiCad has this project open, close it without saving before reopening** — the change
  was a direct file edit.

### 🔌 USB Interface — `USB_Interface.kicad_sch` — ✅ Split out + battery charger added (2026-09-21)

The USB-C connector (J12), CP2102N USB-UART bridge (U11), the DTR/RTS auto-reset
transistors (Q2/Q3, R5–R10), and their decoupling caps (C18–C22) were moved out of the
top-level TX schematic into their own hierarchical sub-sheet, referenced from the root
sheet via a `sheet` symbol (Sheetname "USB Interface"). Every net crossing the sheet
boundary (`USB_DP`, `USB_DM`, `VBUS_5V`, `CC1_NET`, `CC2_NET`, `DTR_SIGNAL`, `RTS_SIGNAL`,
`EN`, `BOOT_IO0`, `U0TXD`/`U0RXD`, plus `+3V3`/`GND`) was already a global label or power
symbol, so no sheet pins were needed — the sub-sheet has none.

Added to the sub-sheet: a **USB-C battery charger** (U12, `MCP73831-2-OT`) that takes
`VBUS_5V` and charges the same `+BATT` net the main pack (J8, XT30) is on, so plugging in
USB-C tops up whatever battery is connected there. R11 (10k) sets the PROG current to a
conservative ~100 mA (`Ireg = 1000/R11[kΩ]`) — swap for ~2k (~500 mA) if faster charging of
a larger pack is wanted. D1 is a charge-status LED (lit while charging, STAT pulled low).
C23/C24 are the datasheet-recommended 1 µF bypass caps on VDD/VBAT. A `PWR_FLAG` on
`VBUS_5V` tells ERC that net is driven from outside the schematic (matches the project's
existing convention elsewhere).

**Still to do:** lay out U12/R11/R12/C23/C24/D1 on the PCB (they only exist in the
schematic/netlist so far) and re-run ERC/DRC in KiCad. **If KiCad has this project open,
close it without saving before reopening** — the split was done by direct file edit, and
saving from the old in-memory (still-flat) schematic would overwrite this change.

### 📡 Transmitter — `TX_50MHz_1W.kicad_sch` — ✅ Fully wired (2026-09-09)

The TX schematic was rebuilt end-to-end: every symbol now uses its real `Kraft6M:*` library
definition (with actual pins, not the empty placeholder cache), reference designators are
assigned (U1–U8, Q1, FL1, Y1, C1–C11, L1–L5, J1–J11), and all nets are connected —
the RF chain (Si5351A → gate-match → PA → T/R switch → 7-pole LPF → antenna, and the
LNA → mixer → IF filter → ESP32 telemetry return path), the I2C bus (ESP32 ↔ Si5351A ↔
dual ADS1115 ↔ OLED), the 7 stick/aux connectors, and power/ground.

Four library parts that didn't exist yet were added to `KiCad_Libraries/Kraft6M.kicad_sym`
to make this possible: `C_10nF_0603`, `L_150nH_0603` (PA gate-match components called out in
the blueprint but never modeled), `Crystal_26MHz`, `OLED_SH1106_I2C`, plus generic
`JST_XH_2/3/4Pin` and `SMA_Edge` connector symbols.

**Open it in KiCad and check:**
- Run **ERC** (`Inspect → Electrical Rules Checker`) — this was hand-verified for pin coverage
  and valid syntax outside KiCad, but ERC is the authoritative check.
- Component placement is functional but not laid out for a clean PCB import — feel free to
  reposition for readability; the wires will follow if you drag with the wire attached (`G`).
- **Known simplifications to revisit:** the battery-voltage sense line on ADS1115 #2 (`AIN3`)
  is left as a `VBATT_SENSE` net with no divider resistors yet — Kraft6M library has no
  resistor symbol defined. ESP32 `EN` is tied straight to 3V3 (no pull-up R + cap, same
  library gap). Add a generic `Device:R` resistor to the library (or via KiCad's built-in
  `Device` lib) before laying out the PCB.

### 🛩️ Receiver (Airborne) — `rx_n.kicad_sch` — ⬜ Not yet wired

Still requires the manual pass below.

1. **Move (`G`)** the `BGS12PL6` Switch to the Antenna input.
2. Wire **Antenna** → **Switch ANT (Pin 5)**.
3. Wire **Switch RF2 (Pin 1)** → **LNA Input (SPF5043Z Pin 1)**.
4. Wire **Si5351A CLK1 (Pin 7)** → **Switch RF1 (Pin 3)**.
5. Wire **ESP32 GPIO 10** → **Switch CTRL (Pin 4)**.
6. **Move (`G`)** the `INA219` sensor near the Power input block.
7. Wire **INA219 IN+ (Pin 1)** → **BATT+**.
8. Wire **INA219 IN- (Pin 2)** → **ESC / Main Power Rail**.
9. Wire **INA219 SDA / SCL** to the **ESP32 I2C pins**.

### 🛩️ Receiver (Airborne) - `rx_n.kicad_sch`

1. **Move (`G`)** the `BGS12PL6` Switch to the Antenna input.
2. Wire **Antenna** → **Switch ANT (Pin 5)**.
3. Wire **Switch RF2 (Pin 1)** → **LNA Input (SPF5043Z Pin 1)**.
4. Wire **Si5351A CLK1 (Pin 7)** → **Switch RF1 (Pin 3)**.
5. Wire **ESP32 GPIO 10** → **Switch CTRL (Pin 4)**.
6. **Move (`G`)** the `INA219` sensor near the Power input block.
7. Wire **INA219 IN+ (Pin 1)** → **BATT+**.
8. Wire **INA219 IN- (Pin 2)** → **ESC / Main Power Rail**.
9. Wire **INA219 SDA / SCL** to the **ESP32 I2C pins**.

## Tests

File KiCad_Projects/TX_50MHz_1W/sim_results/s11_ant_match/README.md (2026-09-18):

# TX antenna-side low-pass filter — S11/S21 sweep (ngspice)

## Update 2 (2026-09-18): re-tuned cutoff, values applied to the schematic

The "Update 1" fix below restored a working filter, but its cutoff sat at 49.1MHz —
right on top of the 50MHz fundamental — so S21 was already down 5dB and S11 was poor
(VSWR 10.4:1) at the operating frequency. Rescaled the whole ladder by the ratio
needed to move the cutoff to ~70-73MHz (L_new = L_old × fc_old/fc_new, same for C,
which preserves the filter shape and 50Ω impedance level), then rounded to standard
E12 part values:

| Part | Old value | New value |
|---|---|---|
| C2, C5 (outer shunt) | 120pF | **82pF** |
| C3, C4 (inner shunt) | 220pF | **150pF** |
| L3, L4, L5 (series) | 180nH | **120nH** |

These are now the actual values in `TX_50MHz_1W.kicad_sch` and BOM (three new library
parts added to `Kraft6M.kicad_sym`: `C_82pF_0805`, `C_150pF_0805`, `L_120nH_0805`).
Netlist: `lpf_final.cir`. Plot: `lpf_final_s11_s21.png`. Numbers: `lpf_final_results.json`.

### Results (final, as committed)

| Frequency | S11 | S21 | VSWR |
|---|---|---|---|
| 10.7 MHz (IF) | -7.5 dB | -0.84 dB | 2.45 |
| **50 MHz (fundamental)** | **-10.9 dB** | **-0.37 dB** | **1.80** |
| 100 MHz (2nd harmonic) | ~0 dB | -37.6 dB | very high |
| -3dB cutoff | — | **73.3 MHz** | — |

50MHz now lands in a local S11 notch with sub-half-dB insertion loss and a good match
(VSWR 1.8), while still keeping strong 2nd-harmonic rejection (-37.6dB, down from
-67.6dB pre-retune, but still comfortably enough for spurious-emission requirements).
This is the current, final result — the "Update 1" numbers below are superseded.

## Update 1 (2026-09-18): root cause found and fixed

The original analysis below (kept for history) treated L4/C4/L5/C5 as an isolated,
unconnected 4-element network because the analyzer showed no path from the T/R
switch's common port to it. That diagnosis was correct about the *symptom* but not
the cause: it wasn't a missing wire.

**Root cause:** `TX_50MHz_1W.kicad_sch` had a stray wire directly connecting C3's two
pads together `(224.79,78.74)-(224.79,73.66)`, in parallel with a wire from that same
point down to a GND symbol. That short-circuited C3 *and* dragged the L3/L4 junction
to GND with it — which is exactly what made the switch-side cluster (U3/C2/L3) and the
antenna-side cluster (L4/C4/L5/C5) look like two disconnected dead-ends. Removing that
one wire (plus two now-meaningless junction dots at the same points) reveals the real,
already-intended topology: a complete **7-pole Pi low-pass filter** from the switch
common port to the antenna —

```
U3.5 (common) -- C2(120pF) shunt -- L3(180nH) series -- Node1
  -- C3(220pF) shunt -- L4(180nH) series -- Node2
  -- C4(220pF) shunt -- L5(180nH) series -- Node_out
  -- C5(120pF) shunt -- J11 (antenna)
```

The symmetric value pattern (120pF outer caps / 220pF inner caps / 180nH×3, matching
the "7-pole LPF" called out in `work_instructions.md`) confirms this was the intended
design — C3 was never a dead no-op part, it was just shorted out by the stray wire.

Re-simulated as a proper 2-port network (`lpf_7pole.cir`, matched-source/load method,
Z0=50Ω both ports): plot is `lpf_7pole_s11_s21.png`, numbers in `lpf_results.json`.

### Results (post-fix)

| Frequency | S11 (return loss) | S21 (insertion loss) | VSWR |
|---|---|---|---|
| 10.7 MHz (IF) | -6.4 dB | -1.1 dB | 2.85 |
| **50 MHz (fundamental)** | **-1.7 dB** | **-5.0 dB** | **10.4** |
| 100 MHz (2nd harmonic) | ~0 dB | -67.6 dB | very high |
| -3dB cutoff | — | **49.1 MHz** | — |

**The filter now works correctly as a low-pass** — 2nd-harmonic rejection at 100MHz is
excellent (-67.6dB). But the **-3dB cutoff lands at 49.1MHz, essentially right on top of
the 50MHz operating frequency**, instead of comfortably above it. That's why S21 at
50MHz is already down 5dB and S11 is poor (VSWR 10.4:1) — the fundamental sits in the
filter's roll-off knee, not in its flat passband. Normal part tolerance (5-10% on these
caps/inductors) could shift the actual cutoff either side of 50MHz unpredictably.

**Recommendation:** scale L3/L4/L5/C2-C5 down slightly to push the cutoff to roughly
65-75MHz (comfortably above 50MHz, still well below 100MHz) before finalizing the BOM.

## Assumptions / model fidelity

- Ideal L/C values from the schematic (no ESR/ESL, no PCB parasitics — routing isn't
  final yet).
- 50Ω assumed on both the switch-side and antenna-side ports; the real T/R switch
  output impedance and antenna feedpoint impedance haven't been verified against
  datasheets.

---

## Original analysis (2026-09-18, superseded above)

Kept for history — this treated the antenna-side cluster as an isolated 4-element
network before the real cause (shorted C3) was found. Netlist: `ant_pi_match.cir`.
Plot: `s11_ant_pi_match.png`. Numbers: `s11_results.json`.

Original conclusion: "node A is not currently wired to anything else... the network
resonates at ~39.6MHz rather than 50MHz." The disconnection diagnosis was a downstream
symptom of the C3 short, not a separate wiring gap — no missing wire needed to be
added, just the stray short removed. The frequency-placement concern raised there
carries forward into the corrected result above (cutoff too close to 50MHz).

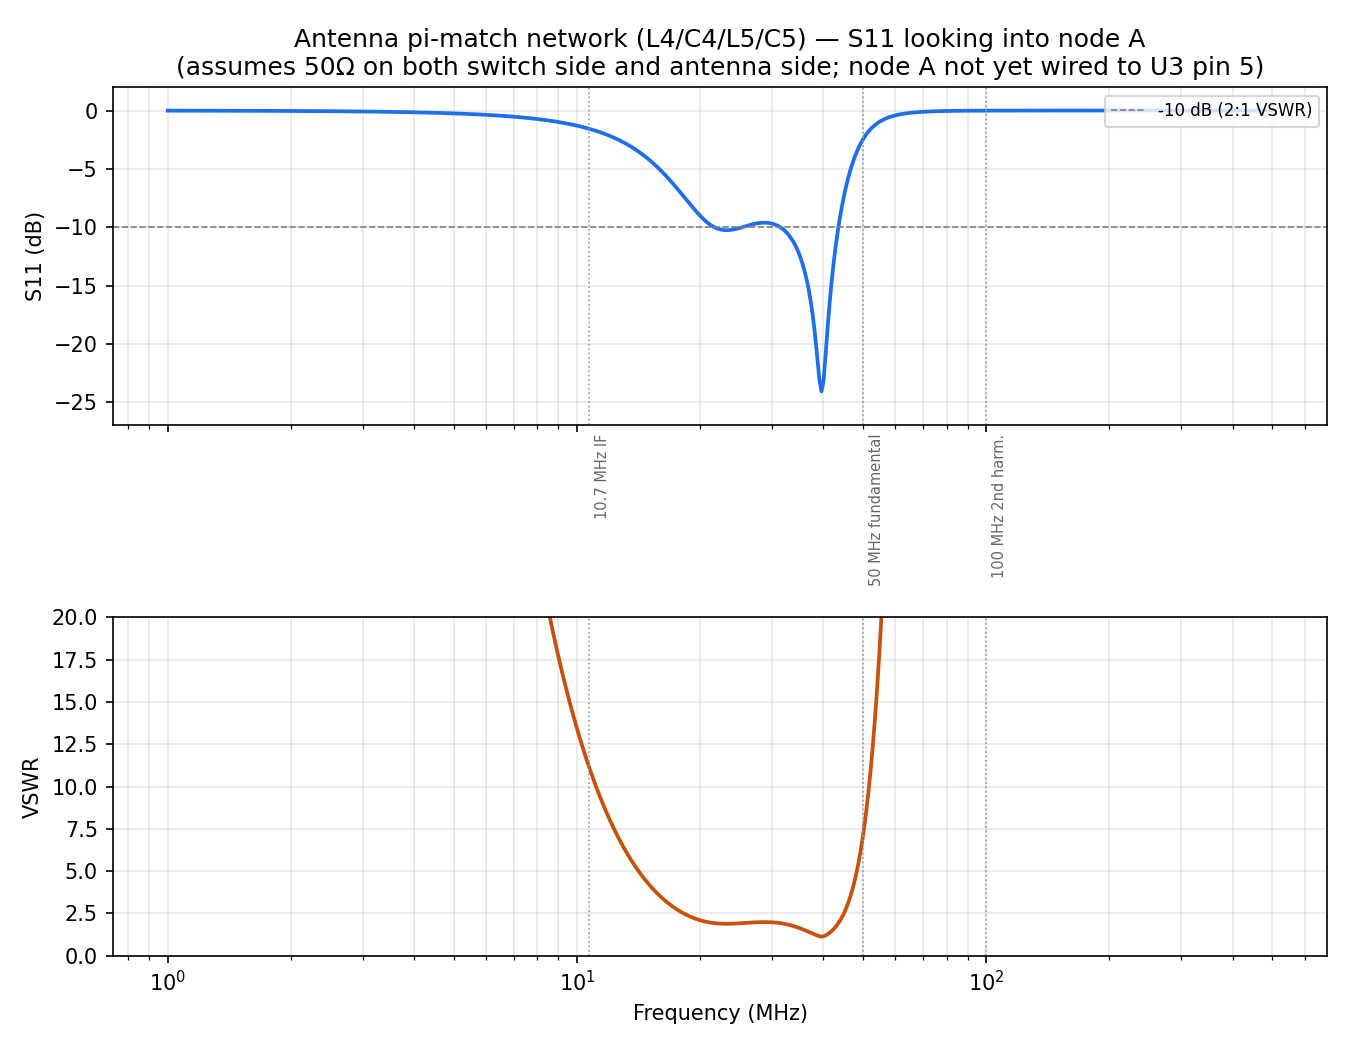
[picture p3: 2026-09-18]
KiCad_Projects/TX_50MHz_1W/sim_results/s11_ant_match/s11_ant_pi_match.png

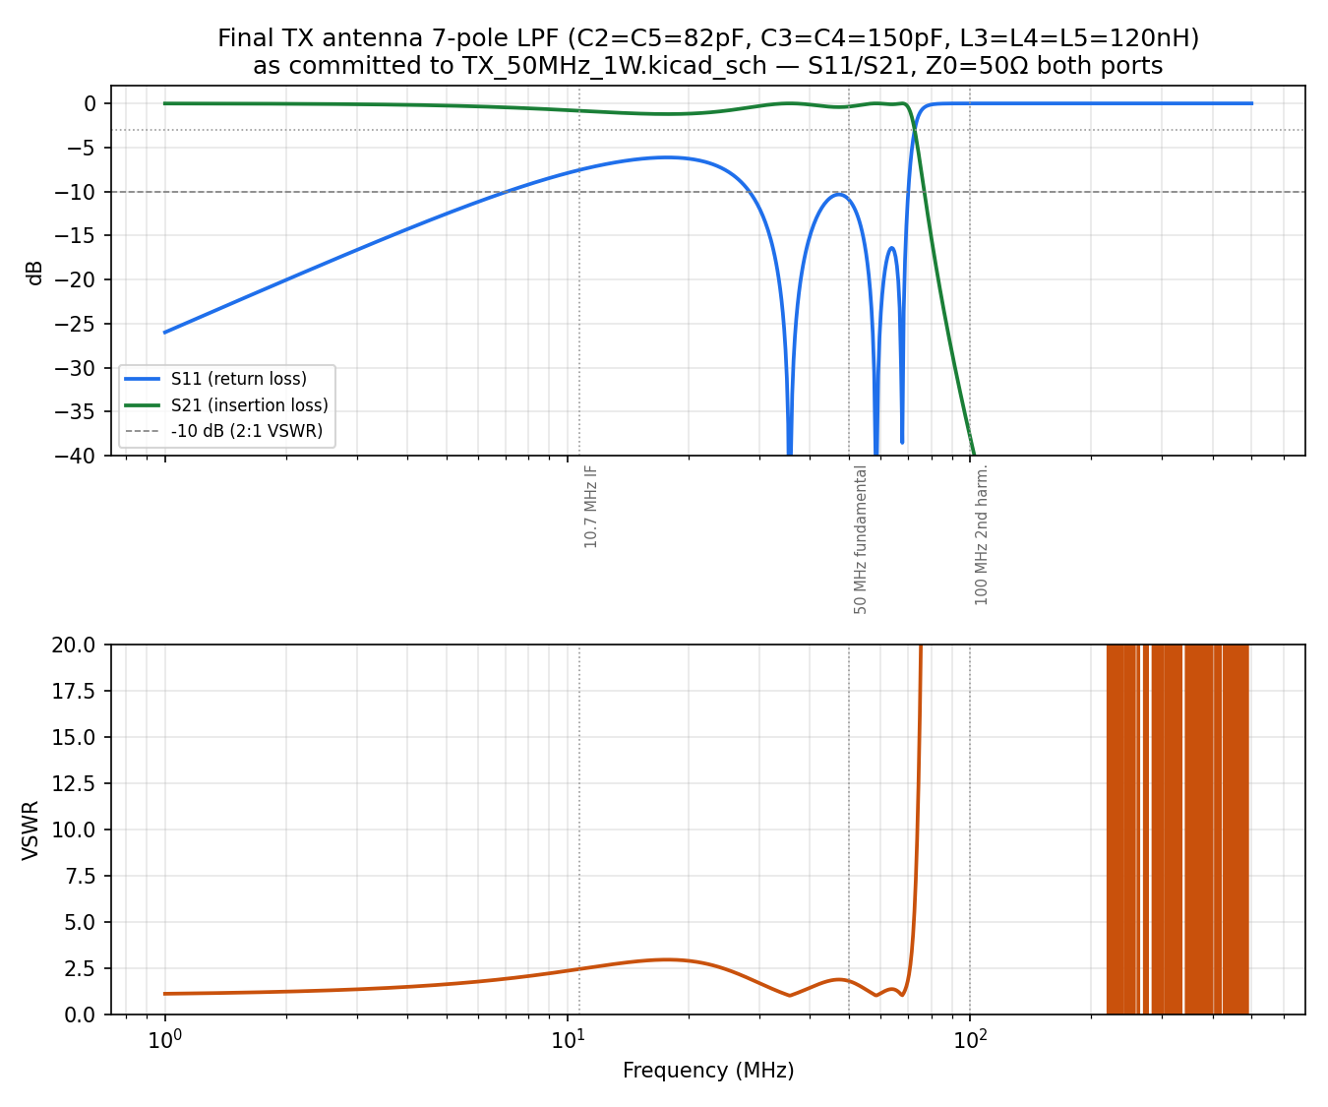
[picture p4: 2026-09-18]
KiCad_Projects/TX_50MHz_1W/sim_results/s11_ant_match/lpf_final_s11_s21.png

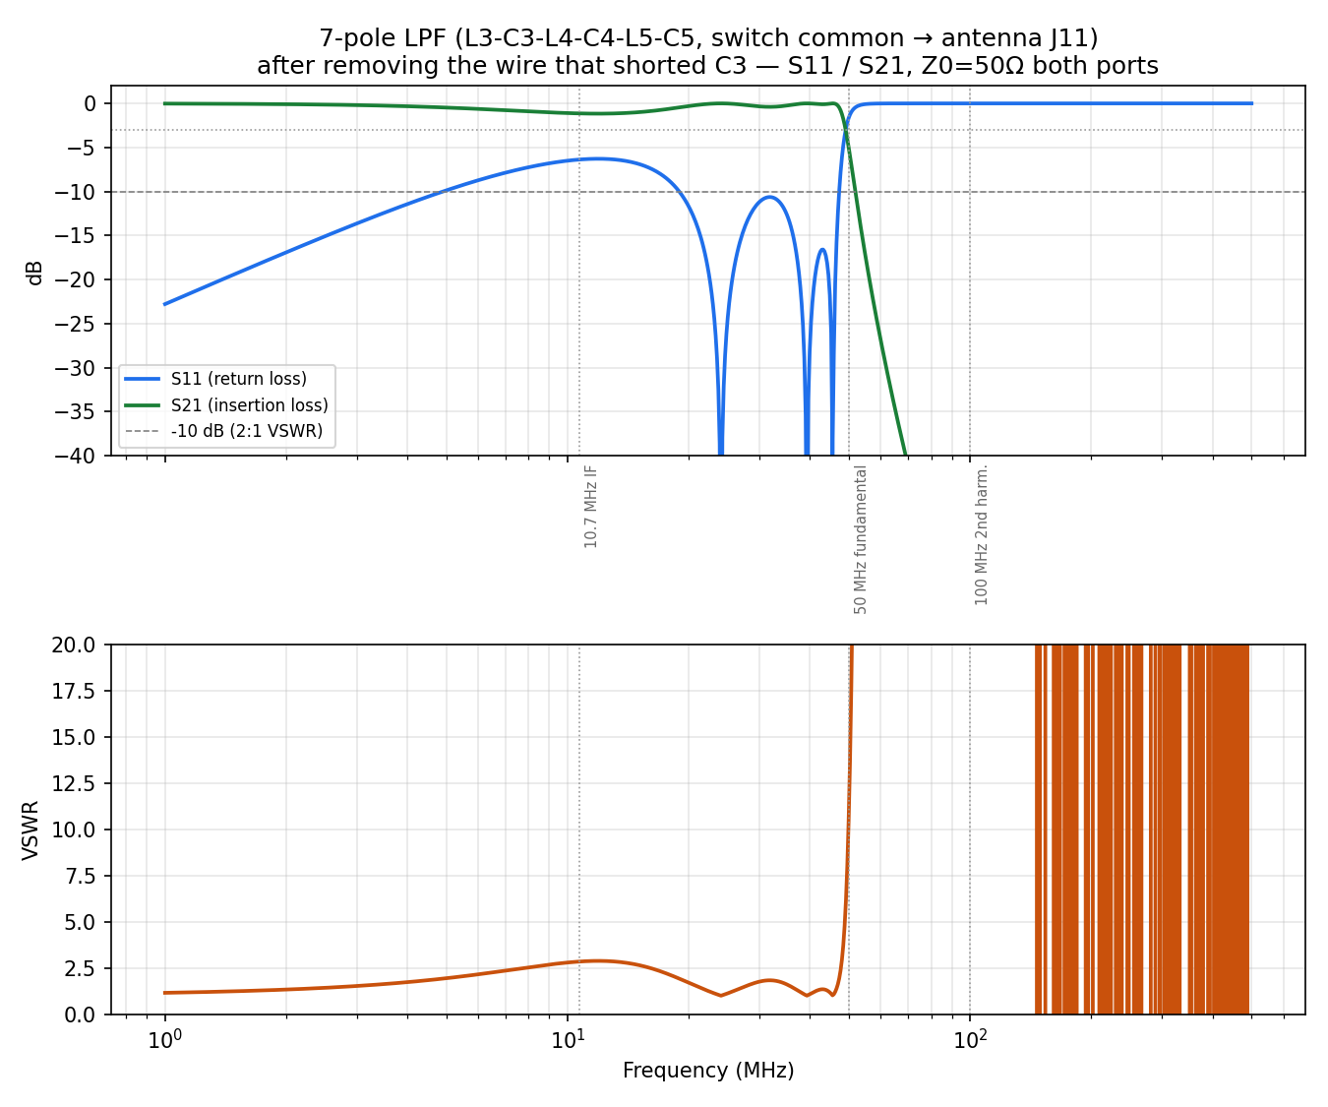
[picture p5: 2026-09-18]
KiCad_Projects/TX_50MHz_1W/sim_results/s11_ant_match/lpf_7pole_s11_s21.png

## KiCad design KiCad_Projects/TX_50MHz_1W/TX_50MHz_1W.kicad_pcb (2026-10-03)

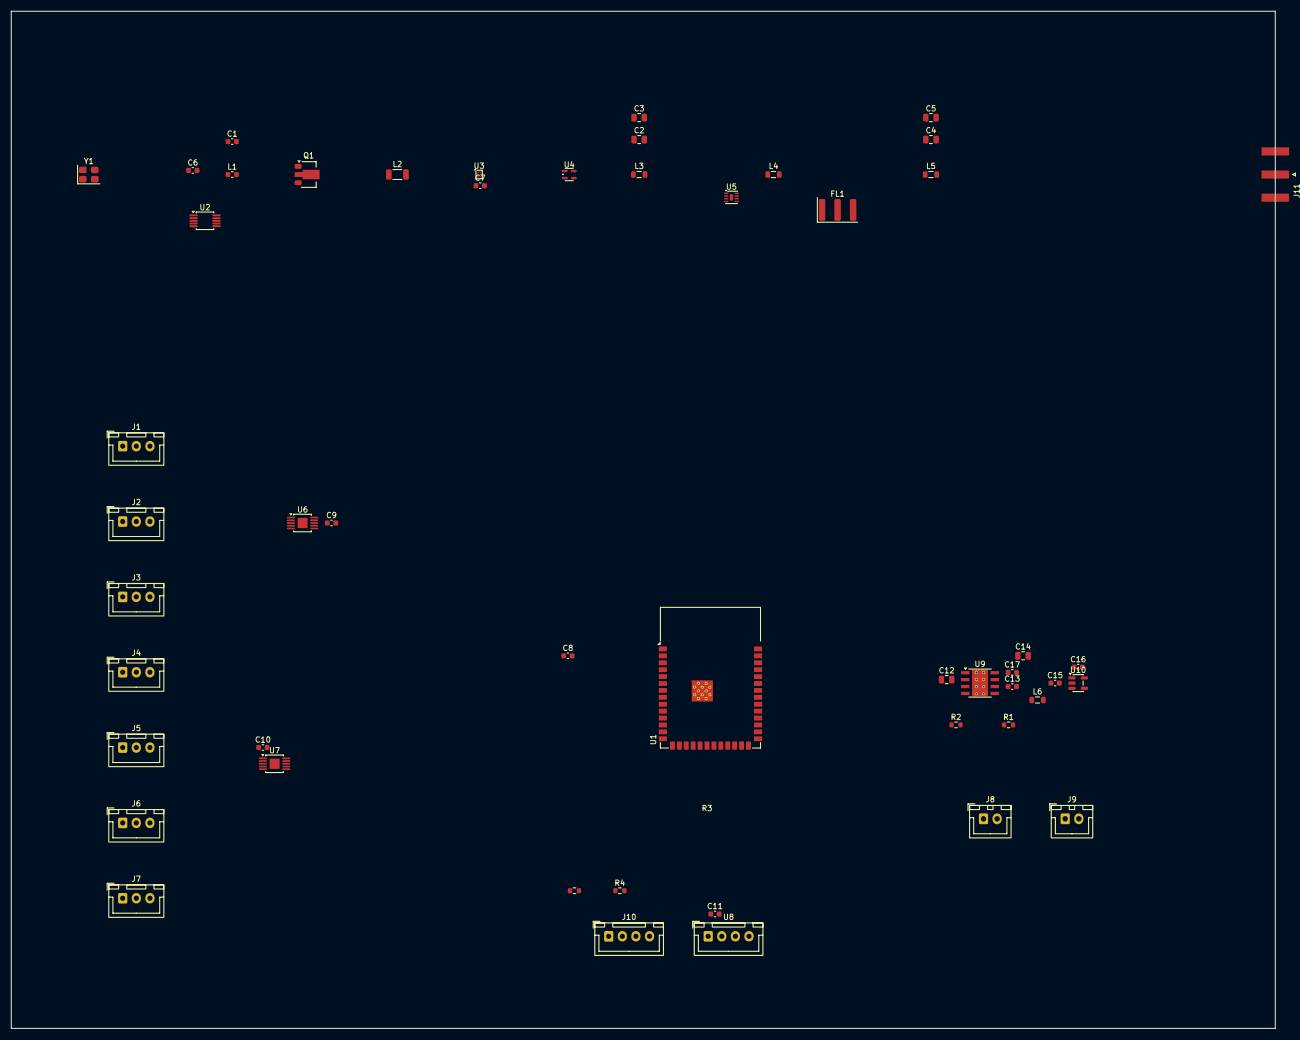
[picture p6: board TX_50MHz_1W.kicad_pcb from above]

Board: 2 copper layers, 232.3 x 186.9 mm, 51 parts (0 on the bottom side), 32 nets, no tracks yet.

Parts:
C1, C17: 10nF; C_0603_1608Metric
C2, C5: 120pF; C_0805_2012Metric
C3, C4: 220pF; C_0805_2012Metric
C6, C7, C8, C9, C10, C11: 0.1uF; C_0603_1608Metric
C12: 10uF; C_0805_2012Metric
C13, C15, C16: 1uF; C_0603_1608Metric
C14: 22uF; C_0805_2012Metric
FL1: 10.7MHz Murata SFE; Resonator_SMD_Murata_SFECV-3Pin_6.9x2.9mm
J1: AIL Stick; JST_XH_B3B-XH-A_1x03_P2.50mm_Vertical
J2: ELE Stick; JST_XH_B3B-XH-A_1x03_P2.50mm_Vertical
J3: THR Stick; JST_XH_B3B-XH-A_1x03_P2.50mm_Vertical
J4: RUD Stick; JST_XH_B3B-XH-A_1x03_P2.50mm_Vertical
J5: AUX6; JST_XH_B3B-XH-A_1x03_P2.50mm_Vertical
J6: AUX5; JST_XH_B3B-XH-A_1x03_P2.50mm_Vertical
J7: AUX7; JST_XH_B3B-XH-A_1x03_P2.50mm_Vertical
J8: V_BATT In (XT30); JST_XH_B2B-XH-A_1x02_P2.50mm_Vertical
J9: 5V Logic In; JST_XH_B2B-XH-A_1x02_P2.50mm_Vertical
J10: I2C Exp / OLED; JST_XH_B4B-XH-A_1x04_P2.50mm_Vertical
J11: ANT; SMA_Amphenol_132289_EdgeMount
L1: 150nH; L_0603_1608Metric
L2: 1.0uH (RFC); L_1206_3216Metric
L3, L4, L5: 180nH; L_0805_2012Metric
L6: 10uH; L_0805_2012Metric
Q1: RD01MUS2 (1W PA); SOT-89-3
R1: 40.2k; R_0603_1608Metric
R2: 10.2k; R_0603_1608Metric
R3, R4: 4.7k; R_0603_1608Metric
U1: ESP32-S3-WROOM-1-N16R8; ESP32-S3-WROOM-1
U2: Si5351A-B-GT; MSOP-10_3x3mm_P0.5mm
U3: BGS12SN6E6327XTSA1 (T/R SW); Infineon_PG-TSNP-6-10_0.7x1.1mm_0.7x1.1mm_P0.4mm
U4: SPF5043Z (LNA); SOT-343_SC-70-4
U5: LT5560 (Mixer); DFN-8-1EP_2x2mm_P0.5mm_EP0.6x1.2mm
U6: ADS1115IDGSR (0x48); HVSSOP-10-1EP_3x3mm_P0.5mm_EP1.83x1.89mm
U7: ADS1115IDGSR (0x49); HVSSOP-10-1EP_3x3mm_P0.5mm_EP1.83x1.89mm
U8: SH1106 1.3in OLED; JST_XH_B4B-XH-A_1x04_P2.50mm_Vertical
U9: LMR33630BDDA; Texas_HSOP-8-1EP_3.9x4.9mm_P1.27mm_ThermalVias
U10: AP2112K-3.3TRG1; SOT-23-5
Y1: 26.000MHz; Crystal_SMD_3225-4Pin_3.2x2.5mm

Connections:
5V: C14.2, C15.2, J9.1, L6.2, R1.1, U7.7, U10.1, U10.3
+3V3: C6.1, C7.1, C8.1, C9.1, C10.1, C11.1, C16.2, J1.1, J2.1, J3.1, J4.1, J5.1, J6.1, J7.1, J10.1, R3.1, R4.1, U1.2, U1.3, U2.1, U2.9, U3.4, U5.3, U5.4, U6.8, U7.1, U7.8, U8.1, U10.5
ADC_IN: FL1.3, U1.13
GND: C2.1, C3.1, C3.2, C4.1, C5.1, C6.2, C7.2, C8.2, C9.2, C10.2, C11.2, C12.1, C13.2, C14.1, C15.1, C16.1, FL1.2, J1.3, J2.3, J3.3, J4.3, J5.3, J6.3, J7.3, J8.2, J9.2, J10.2, J11.2, L3.2, L4.1, Q1.2, R2.2, U1.1, U1.41, U2.10, U3.2, U4.2, U4.4, U5.2, U5.6, U5.8, U5.9, U6.1, U6.3, U7.3, U8.2, U9.1, U9.9, U10.2
unnamed: C1.2, L1.1
unnamed: C4.2, L4.2, L5.1
unnamed: FL1.1, U5.5
unnamed: J1.2, U6.4
unnamed: J2.2, U6.5
unnamed: J3.2, U6.6
unnamed: J4.2, U6.7
unnamed: J5.2, U7.4
unnamed: J6.2, U7.5
unnamed: J7.2, U7.6
unnamed: J10.3, R3.2, U1.12, U2.4, U6.10, U7.9, U8.3
unnamed: J10.4, R4.2, U1.11, U2.5, U6.9, U7.10, U8.4
unnamed: C5.2, J11.1, L5.2
unnamed: L2.1, Q1.3, U3.3
unnamed: L1.2, Q1.1
unnamed: U1.14, U3.6
unnamed: C1.1, U2.6
unnamed: U2.7, U5.7
unnamed: U2.2, Y1.1
unnamed: U2.3, Y1.2
unnamed: U3.1, U4.1
unnamed: C2.2, L3.1, U3.5
unnamed: U4.3, U5.1
unnamed: C17.2, U9.7
unnamed: R1.2, R2.1, U9.5
unnamed: C17.1, L6.1, U9.8
unnamed: C13.1, U9.6
V_BATT: C12.2, J8.1, L2.2, U9.2, U9.3

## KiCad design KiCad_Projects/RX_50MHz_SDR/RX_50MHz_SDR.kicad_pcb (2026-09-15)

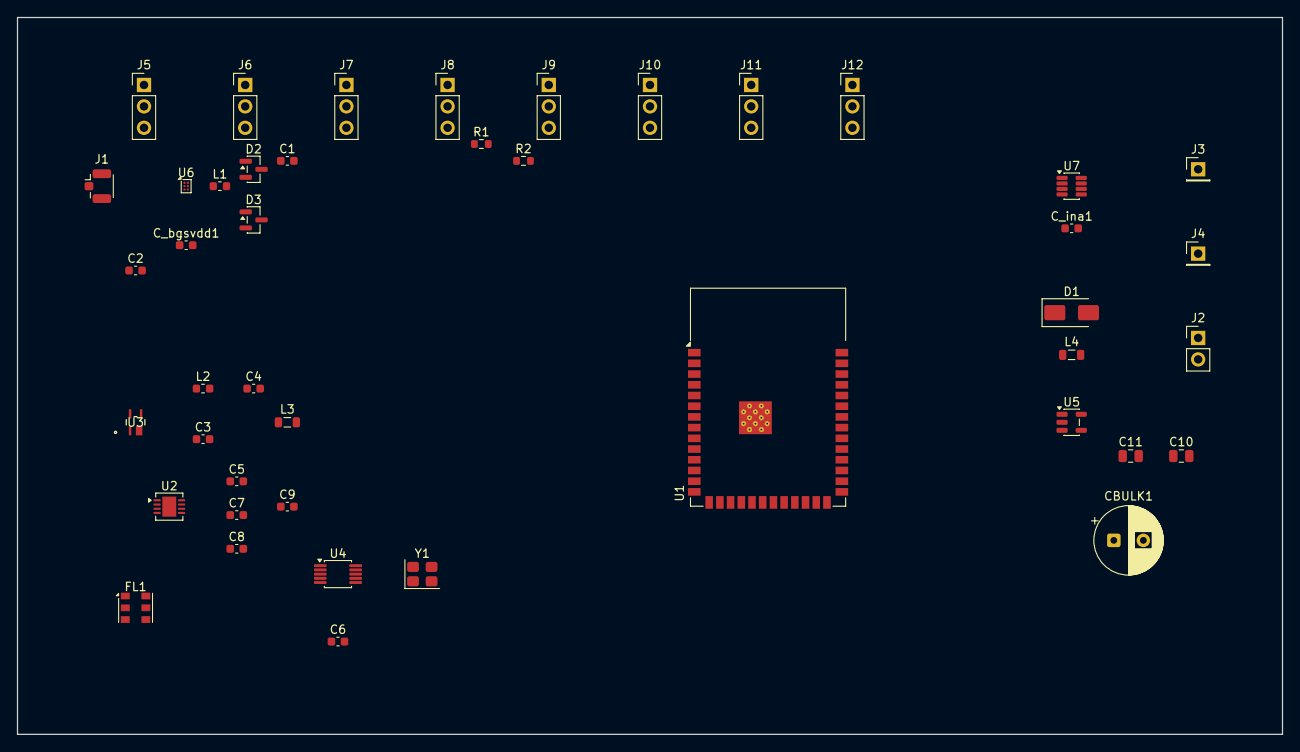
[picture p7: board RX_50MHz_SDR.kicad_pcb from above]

Board: 2 copper layers, 150.0 x 85.0 mm, 44 parts (0 on the bottom side), 35 nets, no tracks yet.

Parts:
C1, C2, C3, C5, C8: 100pF; C_0603_1608Metric
C4, C6, C7: 10nF; C_0603_1608Metric
C9: 0.1uF; C_0603_1608Metric
C10, C11: 10uF; C_0805_2012Metric
CBULK1: 470uF; CP_Radial_D8.0mm_P3.50mm
C_bgsvdd1: 0.1uF; C_0603_1608Metric
C_ina1: 0.1uF; C_0603_1608Metric
D1: SS14; D_SMA
D2, D3: BAV99; SOT-23
FL1: 10.7MHz; Filter_Murata_SFECF-6
J1: ANTENNA; U.FL_Hirose_U.FL-R-SMT-1_Vertical
J2: SERVO_5V_IN; PinHeader_1x02_P2.54mm_Vertical
J3: BATT+; PinHeader_1x01_P2.54mm_Vertical
J4: ESC+; PinHeader_1x01_P2.54mm_Vertical
J5: SERVO1; PinHeader_1x03_P2.54mm_Vertical
J6: SERVO2; PinHeader_1x03_P2.54mm_Vertical
J7: SERVO3; PinHeader_1x03_P2.54mm_Vertical
J8: SERVO4; PinHeader_1x03_P2.54mm_Vertical
J9: SERVO5; PinHeader_1x03_P2.54mm_Vertical
J10: SERVO6; PinHeader_1x03_P2.54mm_Vertical
J11: SERVO7; PinHeader_1x03_P2.54mm_Vertical
J12: SERVO8; PinHeader_1x03_P2.54mm_Vertical
L1, L2: 220nH; L_0603_1608Metric
L3: 1uH; L_0805_2012Metric
L4: 10uH; L_0805_2012Metric
R1, R2: 4.7k; R_0603_1608Metric
U1: ESP32-S3-WROOM-1
U2: LT5560EDD#PBF; DFN-8-1EP_3x3mm_P0.5mm_EP1.65x2.38mm
U3: SPF5043Z; SPF5043Z_QOR
U4: Si5351A-B-GT; MSOP-10_3x3mm_P0.5mm
U5: AP2112K-3.3TRG1; SOT-23-5
U6: BGS12PL6; Infineon_PG-TSNP-6-10_0.7x1.1mm_0.7x1.1mm_P0.4mm
U7: INA219AIDCNR; SOT-23-8
Y1: 26MHz; Crystal_SMD_3225-4Pin_3.2x2.5mm

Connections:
3V3: C6.1, C9.1, C11.1, C_bgsvdd1.1, C_ina1.1, L3.2, R1.1, R2.1, U1.2 (3V3), U1.3 (EN), U2.4 (VCC), U4.1 (VDD), U5.5 (VOUT), U6.6 (VDD), U7.4 (VS)
5V_RAIL: CBULK1.1, D1.1, J2.1, J5.2 (VCC), J6.2 (VCC), J7.2 (VCC), J8.2 (VCC), J9.2 (VCC), J10.2 (VCC), J11.2 (VCC), J12.2 (VCC)
/ADC_IF: FL1.3 (OUT), U1.4 (IO4)
/ANT: J1.1, U6.5 (ANT)
/BATT_POS: J3.1 (1_1), U7.1 (IN+)
/ESC_POS: J4.1 (1_1), U7.2 (IN-)
/LNA_IN: C2.2, D2.1, D3.2, L1.1, U3.3 (RF_IN)
/LNA_OUT_M: C3.1, L2.2
/LNA_OUT_VCC: C4.1, L2.1, L3.1, U3.1 (RF_OUT)
/LO_CLK0: U2.7 (LO+), U4.6 (CLK0)
/MIX_IN_N: C5.1, U2.2 (IN-)
/MIX_LO_N: C8.1, U2.8 (LO-)
/MIX_OUT_N: C7.1, U2.6 (OUT-)
/RF1_NET: C2.1, U6.3 (RF1)
/RX_EN: U1.20 (IO12), U2.3 (EN)
/SCL: R2.2, U1.17 (IO9), U4.4 (SCL), U7.5 (SCL)
/SDA: R1.2, U1.12 (IO8), U4.5 (SDA), U7.6 (SDA)
/SERVO1_SIG: J5.1 (SIG), U1.9 (IO16)
/SERVO2_SIG: J6.1 (SIG), U1.5 (IO5)
/SERVO3_SIG: J7.1 (SIG), U1.6 (IO6)
/SERVO4_SIG: J8.1 (SIG), U1.7 (IO7)
/SERVO5_SIG: J9.1 (SIG), U1.8 (IO15)
/SERVO6_SIG: J10.1 (SIG), U1.10 (IO17)
/SERVO7_SIG: J11.1 (SIG), U1.11 (IO18)
/SERVO8_SIG: J12.1 (SIG), U1.18 (IO10)
/TELEM_TX_PRE: C1.2, U6.1 (RF2)
/TELEM_TX_PRE_B: C1.1, U4.7 (CLK1)
/TR_SW: U1.19 (IO11), U6.4 (CTRL)
/VIN_FILT: D1.2, L4.1
/VIN_LDO: C10.1, L4.2, U5.1 (VIN), U5.3 (EN)
/XTAL_A: U4.2 (XA), Y1.1
/XTAL_B: U4.3 (XB), Y1.2
GND: C4.2, C5.2, C6.2, C7.2, C8.2, C9.2, C10.2, C11.2, CBULK1.2, C_bgsvdd1.2, C_ina1.2, D2.2, D3.1, FL1.2 (GND), J1.2, J2.2, J5.3 (GND), J6.3 (GND), J7.3 (GND), J8.3 (GND), J9.3 (GND), J10.3 (GND), J11.3 (GND), J12.3 (GND), L1.2, U1.1 (GND), U2.9 (EP), U3.2 (GND), U3.4 (GND), U4.8 (GND), U5.2 (GND), U6.2 (GND), U7.3 (GND), U7.7 (A0), U7.8 (A1)
unnamed: FL1.1 (IN), U2.5 (OUT+)
unnamed: C3.2, U2.1 (IN+)

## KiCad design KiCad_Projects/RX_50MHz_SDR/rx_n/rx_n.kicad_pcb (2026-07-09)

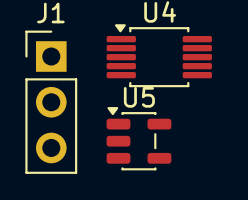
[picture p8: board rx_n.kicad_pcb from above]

Board: 2 copper layers, 3 parts (0 on the bottom side), 2 nets, no tracks yet.

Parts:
J1: Servo_1; PinHeader_1x03_P2.54mm_Vertical
U4: Si5351A; MSOP-10_3x3mm_P0.5mm
U5: AP2112K-3.3; SOT-23-5

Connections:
+3V3: U4.1, U5.5
GND: J1.3, U4.7, U5.2

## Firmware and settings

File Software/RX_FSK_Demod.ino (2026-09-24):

/*
 * 50MHz RC Receiver - IF-undersampling FSK demodulator (ESP32-S3)
 *
 * Implements RX_Design_Details.md / Firmware_Implementation.md section 2:
 *   Undersample IF -> digital down-conversion (I/Q) -> phase discriminator -> bit slicer.
 *
 * IMPORTANT -- read before wiring this to the real IF filter:
 * The ESP32-S3's ADC continuous-mode driver is hardware-capped at
 * SOC_ADC_SAMPLE_FREQ_THRES_HIGH = 83,333 Hz (esp32s3/soc_caps.h), not the 2.5Msps the
 * design doc assumed. That's fine for the FSK signal itself (Carson's-rule bandwidth is
 * only ~15kHz at 5kHz deviation / 2400 baud), but the BOM's 10.7MHz ceramic filter
 * (Murata SFE, ~230kHz bandwidth) is far wider than this ADC can Nyquist-sample without
 * aliasing -- everything within that 230kHz window folds into the decoded signal as noise.
 * Before relying on this: either narrow the IF filter to roughly match the FSK signal's
 * occupied bandwidth (~20-30kHz), or add an analog discriminator ahead of the ADC instead
 * of undersampling the raw IF. See chat discussion for the tradeoff.
 *
 * Library note: no off-the-shelf FSK/DSP library is used. Arduino's analogContinuous()
 * only returns *averaged* results per callback (see esp32-hal-adc.h) -- unusable for
 * per-sample I/Q down-conversion -- so this talks to the IDF adc_continuous driver
 * directly. Requires arduino-esp32 core 3.x (IDF 5.x); the classic core 2.x bundled by
 * the stock PlatformIO "espressif32" registry package predates this driver on the S3.
 */

#include <Arduino.h>
#include "esp_adc/adc_continuous.h"
#include "fsk_demod_core.h"

// ASSUMED, per the schematic's own note ("ASSUMED (not specified in source docs): ESP32
// GPIO nums for TR_SW, RX_EN, ADC_IF"). Must be an ESP32-S3 ADC1 pin (GPIO1-10). Update
// once the schematic's ADC_IF net is pinned to a real GPIO.
#ifndef ADC_IF_PIN
#define ADC_IF_PIN 4
#endif

#define SAMPLE_RATE_HZ    83106u              // 4*10.7MHz/515 -- see quarter-IF derivation below
#define IF_ALIAS_HZ       (SAMPLE_RATE_HZ / 4) // true 10.7MHz IF aliases here by construction
#define FSK_DEVIATION_HZ  5000u                // matches Si5351_GFSK_Driver.cpp
#define FSK_BAUD          2400u

/*
 * Quarter-IF sample rate derivation:
 * Bandpass/undersampling requires Fs = 4*Fif/(2k+1) for some integer k, which places the
 * alias exactly at Fs/4 -- no NCO frequency search needed, the ratio is exact by construction.
 * Solving for the largest Fs <= 83333 Hz with Fif = 10.7MHz gives k=257 -> Fs = 83106.8 Hz.
 */

static adc_continuous_handle_t s_adc_handle = nullptr;
static FskDemod s_demod(SAMPLE_RATE_HZ, IF_ALIAS_HZ, FSK_BAUD, FSK_BAUD * 3.0f);
static int32_t s_dc_offset = 2048; // TODO: measure at boot with RX_EN low, or track with a slow LPF

static bool IRAM_ATTR onConvDone(adc_continuous_handle_t handle, const adc_continuous_evt_data_t *edata, void *user_data) {
    // Just needs to exist for the driver's internal signaling; actual sample handling
    // happens in pollAdcAndDemod() via adc_continuous_read().
    return false;
}

static void setupContinuousAdc() {
    adc_unit_t unit;
    adc_channel_t channel;
    ESP_ERROR_CHECK(adc_continuous_io_to_channel(ADC_IF_PIN, &unit, &channel));

    adc_continuous_handle_cfg_t handle_cfg = {
        .max_store_buf_size = 4096,
        .conv_frame_size = 256,
    };
    ESP_ERROR_CHECK(adc_continuous_new_handle(&handle_cfg, &s_adc_handle));

    static adc_digi_pattern_config_t pattern[1] = {};
    pattern[0].atten = ADC_ATTEN_DB_11;
    pattern[0].channel = channel;
    pattern[0].unit = unit;
    pattern[0].bit_width = SOC_ADC_DIGI_MAX_BITWIDTH;

    adc_continuous_config_t dig_cfg = {
        .pattern_num = 1,
        .adc_pattern = pattern,
        .sample_freq_hz = SAMPLE_RATE_HZ,
        .conv_mode = ADC_CONV_SINGLE_UNIT_1,
        .format = ADC_DIGI_OUTPUT_FORMAT_TYPE2,
    };
    ESP_ERROR_CHECK(adc_continuous_config(s_adc_handle, &dig_cfg));

    adc_continuous_evt_cbs_t cbs = { .on_conv_done = onConvDone };
    ESP_ERROR_CHECK(adc_continuous_register_event_callbacks(s_adc_handle, &cbs, nullptr));

    ESP_ERROR_CHECK(adc_continuous_start(s_adc_handle));
}

static uint8_t s_read_buf[1024];

void pollAdcAndDemod() {
    uint32_t out_len = 0;
    esp_err_t err = adc_continuous_read(s_adc_handle, s_read_buf, sizeof(s_read_buf), &out_len, 0);
    if (err != ESP_OK) return;

    for (uint32_t i = 0; i < out_len; i += SOC_ADC_DIGI_RESULT_BYTES) {
        adc_digi_output_data_t *p = (adc_digi_output_data_t *)&s_read_buf[i];
        int32_t raw = p->type2.data;
        bool bit;
        if (s_demod.processSample(raw, s_dc_offset, &bit)) {
            // TODO: hand `bit` to a bit/byte assembler + the ELRS-style packet framer
            // described in Firmware_Implementation.md section 3.
        }
    }
}

void setup() {
    Serial.begin(115200);
    setupContinuousAdc();
}

void loop() {
    pollAdcAndDemod();
}

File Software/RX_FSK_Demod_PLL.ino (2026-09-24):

/*
 * 50MHz RC Receiver - FSK bit recovery for the PLL-discriminator RX architecture.
 *
 * Hardware: LT5560 mixer -> 10.7MHz IF filter -> CD74HC4046APWR PLL discriminator ->
 * RC low-pass -> ESP32-S3 ADC. See RX_Hardware/RX_Design_Details.md section 3 for why
 * this replaced the original IF-undersampling plan (ESP32-S3 ADC continuous mode tops
 * out at 83.3kSPS -- fine for the FSK signal, but 30x too slow to Nyquist-sample the
 * 230kHz-wide IF filter output; the classic single-chip FM-IF ICs that would have avoided
 * this -- MC3361/MC3362/MC3372, SA604A, NJM2211 -- are all confirmed obsolete as of
 * 2026-09-22).
 *
 * The 4046's loop filter output is already demodulated FSK audio (two DC-ish levels, not
 * two frequencies), so this is just a low-rate baseband sample + bit slicer -- no NCO/DDC
 * needed (contrast with the superseded RX_FSK_Demod.ino). Ordinary analogRead() polling
 * at a modest rate is sufficient; no continuous/DMA ADC driver required.
 */

#include <Arduino.h>
#include "fsk_baseband_slicer.h"

#ifndef ADC_IF_PIN
#define ADC_IF_PIN 4  // ASSUMED -- update once the schematic's ADC_IF net is pinned to a real GPIO
#endif

#define SAMPLE_RATE_HZ  20000u  // ~8x oversample at 2400 baud; well within analogRead() polling rate
#define FSK_BAUD        2400u

static hw_timer_t *s_sample_timer = nullptr;
static volatile bool s_sample_due = false;

static FskBasebandSlicer s_slicer(SAMPLE_RATE_HZ, FSK_BAUD,
                                   /*signal_lpf_cutoff_hz=*/FSK_BAUD * 2.0f,
                                   /*center_tracking_cutoff_hz=*/FSK_BAUD / 8.0f);

void IRAM_ATTR onSampleTimer() {
    s_sample_due = true;
}

void setup() {
    Serial.begin(115200);
    analogReadResolution(12);
    analogSetPinAttenuation(ADC_IF_PIN, ADC_11db);

    s_sample_timer = timerBegin(SAMPLE_RATE_HZ);
    timerAttachInterrupt(s_sample_timer, &onSampleTimer);
    timerAlarm(s_sample_timer, 1, true, 0);
}

void loop() {
    if (!s_sample_due) return;
    s_sample_due = false;

    int32_t raw = analogRead(ADC_IF_PIN);
    bool bit;
    if (s_slicer.processSample(raw, &bit)) {
        // TODO: hand `bit` to a bit/byte assembler + the ELRS-style packet framer
        // described in Firmware_Implementation.md section 3.
    }
}

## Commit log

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2026-07-09 Add plan for full digital encoder conversion (Kraft 7 restomod)
2026-07-09 Add detailed wiring schematic and OLED UI design
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2026-07-09 Add detailed PCB design guide for the 50MHz receiver
2026-07-09 Add KiCad schematic blueprint for the 50MHz receiver
2026-07-09 Add Bill of Materials (BOM) for the 50MHz receiver
2026-07-09 Add KiCad schematic blueprint and BOM for the 50MHz transmitter
2026-07-09 Add visual schematic reference images and update blueprints
2026-07-09 Add Battery Management, Telemetry Protocol, and PCB Footprint Guide
2026-07-09 Update TX hardware design with 7-channel analog wiring and connectors
2026-07-09 Complete engineering package: Firmware Skeleton, Case Mod Guide, and RF Range Analysis
2026-07-09 Add Receiver Power Supply design and update blueprints/BOM
2026-07-09 Add Power Input and Logic connectors to TX schematic and BOM
2026-07-09 Add KiCad Netlists and Import Guide for TX and RX
2026-07-09 Generate .kicad_sch schematic files for TX and RX projects
    [RX_50MHz_SDR.kicad_sch, TX_50MHz_1W.kicad_sch, radio.kicad_pcb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]
2026-07-09 Add Firmware Protocol Spec and Si5351 GFSK Driver
2026-07-09 Add .kicad_pro project files for better compatibility with KiCad 8.0+
    [TX_50MHz_1W.kicad_sch]
2026-07-09 Add SPF5043Z datasheet to repository
    [RX_50MHz_SDR.kicad_sch]
2026-07-10 Add Murata 10.7MHz IF filter technical reference
    [rx_n.kicad_sch]
2026-07-17 Update IF filter reference with footprint details and add KiCad library files
    [rx_n.kicad_sch]
2026-07-17 Add PCB Footprint Mapping guide for TX and RX components
2026-07-17 Add custom KiCad part files (Symbols & Footprints) and update library tables
2026-07-17 Fix KiCad symbol library syntax errors (circle and rectangle S-expressions)
2026-07-17 Fix footprint library table encoding for all project folders
2026-07-17 Add passive components (Inductors, Capacitors) to Kraft6M KiCad library and update footprint mapping
2026-07-17 Add BGS12PL6 RF switch and INA219 current sensor to Kraft6M KiCad library
    [rx_n.kicad_sch]
2026-07-17 Synchronize BOMs, Netlist, and Schematic Blueprints with new telemetry hardware
2026-07-17 Update TX Schematic Blueprint and BOM with telemetry receiver hardware
2026-07-17 Add explicit Telemetry Transmitter section to RX BOM
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2026-08-24 Update TX netlist with telemetry receiver stage (T/R Switch, LNA, Mixer, Filter)
2026-08-24 Inject missing telemetry components into TX and RX schematic sheets
    [TX_50MHz_1W.kicad_sch, rx_n.kicad_sch]
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2026-09-09 Sync TX and RX schematic connectivity with target netlists
    Repair the electrical connectivity of both single-sheet schematics so that a
    netlist exported with kicad-cli 10 matches the connectivity described by
    TX_50MHz_1W.net / RX_50MHz_SDR.net and the TX/RX schematic blueprints.
    TX_50MHz_1W.kicad_sch
    - Split the I2C bus: two coincident global labels (I2C_SDA + I2C_SCL on the
    same point at ESP32 IO11) had merged SDA and SCL into one net that also
    dragged in the BGS12PL6 CTRL/RF2 pins and the SPF5043Z RF input. SDA now
    lands on IO8 and SCL on IO9 only.
    - Removed the wire chain that shorted ESP32 IO8..IO11 together.
    - 3V3 rail: every IC VDD sat on an island with just its decoupling cap.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
    [RX_50MHz_SDR.kicad_sch, TX_50MHz_1W.kicad_sch]
2026-09-10 Add project housekeeping: BOM, wiring notes, library, and KiCad backups
    Brings in TX_BOM.md, work_instructions.md, the Kraft6M symbol library,
    KiCad-generated project backups/env files, and relocates the project
    lock files to the TX_50MHz_1W folder to match current KiCad state.
2026-09-10 Lay out TX and RX schematics for readability (cosmetic only)
    Both sheets had all content crammed into the top-left corner with
    overlapping connector labels. Repositioned symbols into functional
    bands with generous spacing:
    TX (A3): three bands - TX RF chain (crystal -> Si5351 synth -> RD01MUS2
    PA -> BGS12PL6 T/R switch -> 7-element LPF ladder -> ANT) across the
    top with the LPF laid out as one straight line; RX down-conversion
    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
    [RX_50MHz_SDR.kicad_sch, TX_50MHz_1W.kicad_sch]
2026-09-11 impove readabality
    [TX_50MHz_1W.kicad_sch]
2026-09-11 Fix RX schematic net-label readability (cosmetic only)
    Net labels attached to component pins were all authored with a fixed
    orientation (angle 0, justify left) regardless of which side of the
    symbol the pin exits from. For any pin on the left side of a symbol,
    that made the label text render backward into the component body
    instead of outward, stacking on top of the symbol's own pin-name
    text. Rotated 45 such labels 180 degrees (with justify flipped to
    match) across U1, U2, U3, U5, U6, U7, FL1, and all 8 servo headers
    (J5-J12) so every label reads outward into open space.
    Also shortened 13 overly long ESP32 pin names (e.g.
    IO16_SERVO1_AIL -> IO16) that overflowed past the pin stub and
    colli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
    [RX_50MHz_SDR.kicad_sch]
2026-09-11 Fix TX schematic net-label readability (cosmetic only)
    Same issue as the RX schematic: 10 global net labels attached to
    left-exiting pins were authored with a fixed orientation (angle 0,
    justify left), making the label text render backward into the
    component body instead of outward. Rotated 180 degrees (justify
    flipped to right) across U3 (BGS12PL6 T/R switch CTRL pin), C5,
    and headers J1, J2, J8, J9.
    Verified with kicad-cli: netlist export is unchanged (only
    rotation/justify differs) and ERC violation count/types are
    identical before and after - no connectivity was altered.
    TX's ESP32 symbol already uses short pin names, so the pin-name
    shortening done on RX does not apply here.
    Co-Autho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
    [TX_50MHz_1W.kicad_sch]
2026-09-11 Grid-align symbols, wire the RF chain directly, use power symbols
    Three related cosmetic/hygiene passes across both RX and TX schematics,
    each verified with kicad-cli (netlist net-membership diff + ERC) to
    confirm zero unintended connectivity change:
    1. Grid alignment: every symbol placement had a small sub-grid
    fractional offset (not a multiple of the standard 1.27mm/50mil
    KiCad grid), making it impossible to snap new wires onto existing
    pins. Snapped every symbol to the nearest grid point and moved
    everything rigidly attached to it (labels, wire endpoints,
    junctions, no-connect markers) by the same delta.
    2. Filter/amplifier direct wiring: the LNA -> mixer -> filter RF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
    [RX_50MHz_SDR.kicad_sch, TX_50MHz_1W.kicad_sch]
2026-09-15 Wire RX schematic connections, fix footprints, place PCB
    Schematic:
    - Added I2C pull-ups (R1/R2) and grounded the antenna shield pin,
    fixing two real connectivity gaps (missing I2C pull-ups, floating
    U.FL shield) found via ERC.
    - Corrected footprint assignments: J3/J4 (1-pin symbol to match their
    1-pad header footprints), CBULK (legacy footprint name that no
    longer exists), U3 SPF5043Z (missing local library registration),
    and four stale footprint names left over from an older KiCad
    library layout (J1 U.FL, U6 BGS12PL6, U1 ESP32-S3, U2 LT5560 -
    the last of which was also missing its exposed-pad ground pin).
    - Replaced all label-only signal connections (28 nets: servo signals,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
    [RX_50MHz_SDR.kicad_pcb, RX_50MHz_SDR.kicad_sch]
2026-09-15 Update TX schematic/PCB and Kraft6M library (in-progress KiCad edits)
    These files were modified outside this session (likely a parallel
    KiCad GUI session on TX while RX work was in progress this
    conversation) and are being committed as-is alongside the RX changes.
    Includes a new TX_50MHz_1W.kicad_pcb. ERC sanity-checked clean load
    before committing; content not otherwise reviewed by Claude.
    [TX_50MHz_1W.kicad_pcb, TX_50MHz_1W.kicad_sch]
2026-09-18 Add ngspice S11 sweep for TX antenna pi-match network
    Simulates the L4/C4/L5/C5 network the schematic analyzer detected near
    J11, since the actual T/R switch common port (U3 pin 5) isn't wired to
    it yet. Result: the network resonates near 40MHz rather than the
    board's 50MHz design frequency (S11=-2.5dB / VSWR 6.9:1 at 50MHz),
    worth re-checking before finalizing values. Also flags C3 as a dead
    no-op capacitor (both pads on GND).
2026-09-18 Fix shorted C3 in TX antenna LPF, re-run S11/S21
    Removed a stray wire in TX_50MHz_1W.kicad_sch that shorted C3's two
    pads together and dragged the L3/L4 junction to GND. That short was
    the actual cause of the earlier "disconnected antenna network" finding
    -- with it removed, L3-C3-L4-C4-L5-C5 forms the complete 7-pole
    low-pass filter the value pattern (120/220/220/120pF, 3x180nH) always
    implied, running from the T/R switch common port to the antenna.
    Re-simulated as a proper 2-port network: the filter now works (-67.6dB
    rejection at the 100MHz 2nd harmonic), but the -3dB cutoff sits at
    49.1MHz -- right on top of the 50MHz fundamental instead of safely
    above it, so S21 is already down 5dB an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
    [TX_50MHz_1W.kicad_sch]
2026-09-18 Re-tune TX antenna LPF cutoff away from 50MHz, verify with SPICE
    Frequency-scaled the 7-pole ladder (L_new = L_old * fc_old/fc_new, same
    for C, preserving shape and 50ohm impedance) to move the -3dB cutoff
    from 49.1MHz to ~73MHz, then rounded to standard E12 parts:
    C2/C5: 120pF -> 82pF, C3/C4: 220pF -> 150pF, L3/L4/L5: 180nH -> 120nH
    Added the three new values to Kraft6M.kicad_sym (library is shared
    with the RX project; only new symbols were added, nothing existing
    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
    [TX_50MHz_1W.kicad_sch]
2026-09-24 Add firmware CI: native self-tests and ESP32-S3 sketch builds
    Tracks the RX FSK demod sketches, their header-only cores and native
    self-tests, and adds a GitHub Actions workflow that runs the self-tests
    and compiles every sketch for esp32:esp32:esp32s3.
2026-09-28 Move receive chain to Si4463 upconversion; fix RX/TX schematic wiring
    Replace the 10.7MHz IF + CD74HC4046A PLL discriminator with an LT5560
    upconverter (Si5351 LO fixed at 118.2MHz) into a ~169MHz LC band-pass and
    a Si4463-C2A-GM FSK packet receiver on SPI, on both the RX board and the
    TX board's telemetry receiver. AX5043 rejected (out of production), CC1101
    rejected (LO would exceed the Si5351's range).
    Docs: design details, blueprints, BOMs, layout/power guides, firmware and
    protocol specs, system docs and block diagrams updated to the new chain.
    RX schematic: add Si4463 section; fix servo pins shorted onto one net,
    I2C not reaching the ESP32, antenna bypassing the T/R switch, LNA not
    r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
    [RX_50MHz_SDR.kicad_sch, TX_50MHz_1W.kicad_pcb, TX_50MHz_1W.kicad_sch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]
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2026-10-03 broke up scheamatics into multiple files for easier navigation and organization. Added a new schematic page for organizing the schematics. Added a new schematic page for the RX controller IO. Added a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
    [RX_Controller_IO.kicad_sch, RX_IF_Radio.kicad_sch, RX_RF_Front_End.kicad_sch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]
2026-10-04 udated scheamatic
    [TX_Controller_RF.kicad_sch, USB_Interface.kicad_sch]
2026-10-05 lable correctly, local nets connected
    [RX_50MHz_SDR.kicad_sch, TX_50MHz_1W.kicad_sch, TX_Controller_RF.kicad_sch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]
